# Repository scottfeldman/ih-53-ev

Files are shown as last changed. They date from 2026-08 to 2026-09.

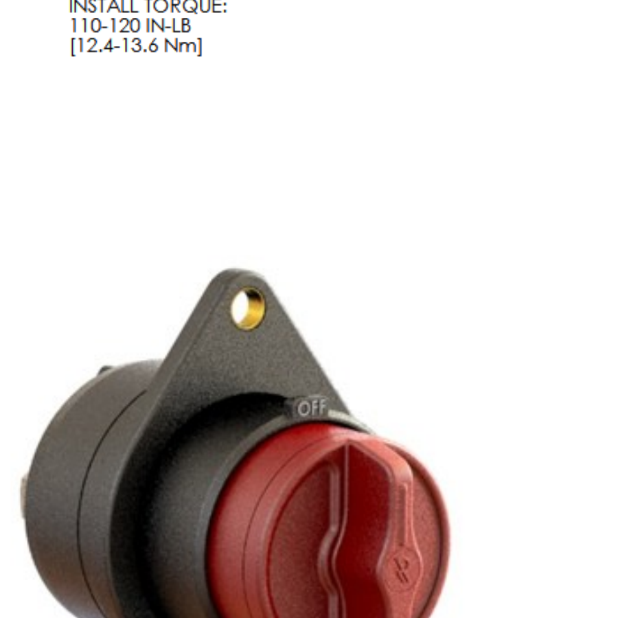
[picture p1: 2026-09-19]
bus bars/photo.png

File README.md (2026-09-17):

# ih-53-ev

1953 International Harvester EV conversion

### Dashboard

Pi 5 + PiCAN 3 instrument panel (Go / Fiber / HTMX): see [`dashboard/README.md`](dashboard/README.md).

### References

[https://www.orionbms.com/manuals/pdf/orionbms2_wiring_manual.pdf](https://www.orionbms.com/manuals/pdf/orionbms2_wiring_manual.pdf)
[https://www.orionbms.com/charger-integration/interfacing-tsm2500-chargers/](https://www.orionbms.com/charger-integration/interfacing-tsm2500-chargers/)
[https://www.thunderstruck-ev.com/images/companies/1/Chargers/ThunderStruck-TSM2500-ManualV1.09.pdf](https://www.thunderstruck-ev.com/images/companies/1/Chargers/ThunderStruck-TSM2500-ManualV1.09.pdf)
[https://www.go-ev.com/PDFs/HyPer_System_User_Manual_RevA_1.pdf](https://www.go-ev.com/PDFs/HyPer_System_User_Manual_RevA_1.pdf)
[https://www.bluesea.com/products/5032/ST_Blade_Split_Bus_Fuse_Block](https://www.bluesea.com/products/5032/ST_Blade_Split_Bus_Fuse_Block)
[https://www.fastandquiet.com/downloadable/600w-dc-dc-converter-isolated-dcis-schematic.PDF](https://www.fastandquiet.com/downloadable/600w-dc-dc-converter-isolated-dcis-schematic.PDF)
[https://www.ewertenergy.com/products/candapter/downloads/candapter_manual.pdf](https://www.ewertenergy.com/products/candapter/downloads/candapter_manual.pdf)
[https://www.raspberrypi.com/products/raspberry-pi-5/](https://www.raspberrypi.com/products/raspberry-pi-5/)
[https://www.raspberrypi.com/products/touch-display-2/](https://www.raspberrypi.com/products/touch-display-2/)
[https://www.raspberrypi.com/documentation/accessories/touch-display-2.html](https://www.raspberrypi.com/documentation/accessories/touch-display-2.html)
[https://www.raspberrypi.com/software/](https://www.raspberrypi.com/software/)

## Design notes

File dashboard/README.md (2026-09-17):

# IH-53 EV dashboard

Go + Fiber + HTMX + Gomponents instrument panel for the Raspberry Pi 5 + PiCAN 3.

Listens on `:10000`, talks **SocketCAN** `can0` at **250 kbps** (BMS-side CAN1 tap). Orion remains the TSM2500 charge master. The dash is **listen-only** for telemetry (Orion broadcasts + TSM2500 status + HyPer TPDOs). The only optional TX is **confirm-clear Orion DTCs** (OBD2 Mode `$04`).

## Hardware

- Pi 5 + [PiCAN 3](https://www.skpang.co.uk/collections/hats/products/pican3-can-bus-board-for-raspberry-pi-4-with-3a-smps-rtc)
- Tap **CAN-PI-H / CAN-PI-L** on Orion CAN1 (same net as CANdapter / TSM2500), **not** the HyPer side of the BB-CANOP isolator — see [`schematic/wires.md`](../schematic/wires.md) §8.5
- PiCAN **120 Ω jumper open** (Orion + HyPer already terminate)
- Bitrate **250000** — ignore `500000` in the [PiCAN Python examples](https://github.com/skpang/PiCAN-Python-examples)

SocketCAN bring-up is done by **systemd-networkd**, not by the process.

## Dev (Mac)

```bash
cd dashboard
GOWORK=off go run ./cmd/dashboard --demo --listen :10000
```

## Build for Pi 5

```bash
cd dashboard
GOWORK=off GOOS=linux GOARCH=arm64 go build -o ih53ev-dashboard ./cmd/dashboard
```

## Install on Pi

Fresh [Raspberry Pi 5](https://www.raspberrypi.com/products/raspberry-pi-5/) plus the official [Touch Display 2 10″](https://www.raspberrypi.com/products/touch-display-2/) (1200×1920). Connection steps: [Touch Display 2 docs](https://www.raspberrypi.com/documentation/accessories/touch-display-2.html). Vehicle wiring (PiCAN 3 SMPS, SW5, CAN tap): [`schematic/wires.md`](../schematic/wires.md) §11.

**PiCAN 3:** the HAT covers the same 5 V/GND pins the display pigtail uses. Use a stacking header and pick 5 V/GND off the top, or tap 5 V/GND on the PiCAN to display J1. In the truck, power from the PiCAN **3 A SMPS** only — do **not** also plug USB-C into the Pi. Leave USB empty.

Flash [Raspberry Pi OS](https://www.raspberrypi.com/software/) (64-bit, **desktop** — not Lite). Enable SSH in Imager customisation.

```bash
git clone https://github.com/scottfeldman/ih-53-ev.git
cd ih-53-ev/dashboard
sudo ./install.sh
sudo reboot
```

`install.sh` builds the dash, enables it on boot as fullscreen Chromium kiosk, and matches the current desktop: landscape 10″ panel, taskbar at the bottom, solid red background, dash icon centered. Reboot is required so the PiCAN overlay can create `can0`; until then the app exits and the browser has nothing to open. After reboot, Chromium fills the screen. Tap **Desktop** (then confirm) to leave kiosk; open **IH-53 EV Dashboard** from the Raspberry menu or the desktop icon to return. If the image is sideways the wrong way, change `DISPLAY_TRANSFORM` in `install.sh` from `90` (Left) to `270` (Right) and re-run.

## Flags

| Flag | Default | Meaning |
|---|---|---|
| `--iface` | `can0` | SocketCAN interface |
| `--listen` | `:10000` | HTTP bind |
| `--demo` | off | Synthetic state, no CAN |
| `--canmap` | auto | Orion + HyPer layout YAML |
| `--log-can` | off | Log every RX frame |

## Orion broadcasts (CAN1)

Telemetry is **push**, not OBD2 poll — so the laptop Orion utility can stay on CAN1 without fighting the dash.

Program custom messages in the Orion utility (**CANBUS Settings → Edit CANBUS Messages**) to match [`canmap.yaml`](canmap.yaml). Standard 11-bit IDs, **big-endian**, CAN1:

| ID | Rate | Contents |
|----|---|---|
| `0x350` | 100 ms | SOC % (u8), pack V (u16 ×0.1), pack A (i16 ×0.1) |
| `0x351` | 100 ms | CCL, DCL (u16 A), high/low/avg temp (°C i8) |
| `0x352` | 500 ms | cell min/max (u16 ×0.0001 V), pack cycles, fault count |

**Cell broadcast** (all 30 taps): Orion utility → CANBUS Settings → **Enable Battery Cell Broadcast** on CAN1, ID **`0x36`** (matches `canmap.yaml`). Each frame is one tap: ID, instant V, IR + shunt bit, open V, checksum. The Detail page shows a **5×6** grid (modules × taps).

For Pack SOC in the utility, set **Then Divide By = 2** so the bus carries whole percent (matches `scale: 1` in the YAML).

The dash does **not** continuously use `0x7E3` / `0x7EB`. Those stay free for the CANdapter utility.

## HyPer X1 TPDOs

Program in TAU SmartView (do not add Node ID). See `hyper:` in [`canmap.yaml`](canmap.yaml): `0x190` / `0x191` / `0x192`.

## TSM2500

Listen-only status `0x18EB2440`. Never transmits `0x18E54024`.

## Commands from the dash?

| Action | On bus? | Notes |
|---|---|---|
| Read SOC / V / A / temps / cells summary | No TX | Orion broadcasts |
| Read charger / X1 | No TX | Status / TPDOs |
| Set charge V/A | **Never** | Orion owns TSM2500 |
| Drive / throttle | **Never** | Analog throttle |
| Clear Orion DTCs | Optional TX | Mode `$04` once; unplug utility first |

Normal operation is **read-only**. Clear-faults is the only command worth keeping on the dash.

## Safety

- Stale sources show **NO DATA**, not the last good value
- Fault clear is POST + browser confirm + `confirm=yes`
- CANdapter and Pi share CAN1; OBD2 conflict only if you clear faults while the utility is live

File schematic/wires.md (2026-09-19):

# IH-53 EV wiring list

Physical wires taken from `IH53EV.kicad_sch`. Size/type is the schematic text on that run when present. **Color prefers the component wiring-harness pigtail** and is carried through splices; schematic stroke color is ignored when a harness color exists.

Inline disconnects (Anderson, DJ70xx, Weather Pack, Deutsch, USB) are drawn as two-sided symbols. Each side is a separate cable termination; mating the housings is not a wire.

**Orion BMS 2 Main I/O** on this vehicle is the **CWHMIO 18 AWG** harness (Sumitomo 8240-4892 crimps), not 22 AWG.

## Color rules

1. If a factory harness / pigtail has a color, that color is the color of the whole run, including splices and bulkhead connectors.
2. When two pigtails meet (for example TSM2500 CAN into Orion CAN1), **keep the Orion (or other “bus owner”) color on the trunk**; the other pigtail keeps its factory color only up to the splice.
3. Traction **2/0 DLO** is **orange** (EV HV jacket). Polarity is **red** (+) / **black** (−) adhesive heatshrink at each lug — not a red/black jacket.
4. 12 V **GXL** (schematic: GLX) battery and DC-DC 12 V feeds have no colored pigtail: **red = +**, **black = −**.
5. Vehicle **DCIS pack HV** (10 AWG / 18 AWG HV from the 3-way toward the pack) is **red = +**, **black = −**. Factory DCIS pigtail stays **yellow / gray** only up to `dj70310-6.3-1`.
6. Orion CWHMIO colors: pin 1 (Always_On) = **green**, pin 2 (READY) = solid **blue**, and pin 3 (CHARGE) = solid **red** (2 and 3 from [Orion’s CANdapter troubleshooting page](https://www.orionbms.com/troubleshooting/problems-connecting-bms-unit-pc-software/); pin 1 from this harness). Pins 6, 7, 13, 14 from this vehicle’s harness. Remaining pins still **verify on harness card**.

## Wire key (from schematic)

| Code | Meaning |
| --- | --- |
| AWG | conductor size |
| TXL | 12 V / 48 V primary (18 AWG on this sheet) |
| GXL | 12 V 10 AWG (schematic label **GLX**) |
| HV | 600–1000 V DC pack (silicone / EV) |
| AC | J1772 / T92 mains (600 V) |
| 300VAC | RAC02 tap only (schematic may say 18AWG AC — same run) |
| DLO | traction / pack 2/0 |

## Harness color map (factory pigtails)

| Device | Pin / lead | Color | Size | Source |
| --- | --- | --- | --- | --- |
| Orion CWHMIO | 1 Always_On_Power | **green** | 18 AWG | this harness |
| Orion CWHMIO | 2 READY_Power | **blue** | 18 AWG | [Orion troubleshooting](https://www.orionbms.com/troubleshooting/problems-connecting-bms-unit-pc-software/) |
| Orion CWHMIO | 3 CHARGE_Power | **red** | 18 AWG | same |
| Orion CWHMIO | 6 Charger_Safety | **red/white** | 18 AWG | this harness |
| Orion CWHMIO | 7 DISCHARGE_enable | **blue/white** | 18 AWG | this harness |
| Orion CWHMIO | 12 Ground | **black** (typical; verify) | 18 AWG | CWHMIO; ground convention |
| Orion CWHMIO | 13 J1772_Control_Pilot | **orange/white** | 18 AWG | this harness |
| Orion CWHMIO | 14 J1772_Proximity_Detect | **brown/white** | 18 AWG | this harness |
| Orion CWHMIO | 17 CAN1_Shield | drain / bare | shield | CWHMIO CAN1 STP |
| Orion CWHMIO | 18 CAN1_H | CAN1 pair (gray jacket STP; inner *verify*) | 18 AWG pair, 12 ft | [purchasing guide](https://www.orionbms.com/manuals/pdf/orionbms2_purchasing_guide.pdf) |
| Orion CWHMIO | 19 CAN1_L | CAN1 pair (with pin 18) | 18 AWG pair, 12 ft | same |
| TSM2500 AC | L / N / PE | **brown** / **blue** / **green-yellow** | 2.5 mm² (~14 AWG) | [TSM2500 manual](https://www.thunderstruck-ev.com/images/companies/1/Chargers/ThunderStruck-TSM2500-ManualV1.09.pdf) |
| TSM2500 DC | + / − | **red** / **black** | 6 mm² (~10 AWG **HV**, not TXL) | same (SB50); pack voltage |
| TSM2500 CAN | H / L | **green/white** / **blue/white** | 0.5 mm² | same; [Orion TSM2500 note](https://www.orionbms.com/charger-integration/interfacing-tsm2500-chargers/) (splice onto Orion CAN1 colors) |
| DCIS output | + / − | **red** / **black** | 6.0 mm² (~10 AWG) | [DCIS schematic](https://www.fastandquiet.com/downloadable/600w-dc-dc-converter-isolated-dcis-schematic.PDF) |
| DCIS input | + / − | factory **yellow** / **gray**; vehicle **red** / **black** | 10 AWG **HV** (factory pigtail 1.5 mm²) | factory pigtail to 3-way; vehicle HV is red/black |
| DCIS key | Key_Switch_Control | **green** | 0.5 mm² | same |
| HyPer 9 encoder (not on this sheet) | K1-35 / 21 / 33 / 9 | red / yellow / green / black | 18 / 20 AWG | [HyPer manual](https://www.go-ev.com/PDFs/HyPer_System_User_Manual_RevA_1.pdf) |
| HyPer 9 K1 CAN, K1-24, K1-25, K1-26 | — | *verify on K1 print* (colors vary by kit) | 18–20 AWG | HyPer manual: identify by pin number |
| HyPer 9 B+ / B− | DC lugs | **orange** jacket; red / black HS | 2/0 DLO | EV orange; polarity by heatshrink |
| CANdapter USB | cable | black jacket (USB 2.0) | USB | CANdapter |

## Connector reference

| Device | Mating connector | Contacts / wire | Source |
| --- | --- | --- | --- |
| Orion BMS 2 Main I/O | TE 1376360-1 | **18 AWG** + Sumitomo 8240-4892 (this harness) | user; [Orion wiring manual](https://www.orionbms.com/manuals/pdf/orionbms2_wiring_manual.pdf) |
| Orion voltage taps (cell taps, not drawn as wires on this sheet) | TE 1318389-1 | 22 AWG + TE 1123343-2 (gold); group colors orange / red / yellow, grounds black | same |
| HyPer 9 X1 K1 | TE AMPSEAL 35-pin 776164-1, pins 770854-1 | typically 18–20 AWG | [HyPer System User Manual](https://www.go-ev.com/PDFs/HyPer_System_User_Manual_RevA_1.pdf) |
| HyPer 9 B+ / B− | inverter DC lugs | 2/0 DLO, ring terminal | schematic |
| TSM2500 AC input | DJ7031-4.8 (`DJ7031-4.8`; 4.8-11 / 4.8-21) | 2.5 mm² (~14 AWG) brown / blue / green-yellow | TSM2500 manual; schematic |
| TSM2500 DC output | Anderson SB50 (`AndersonSB50`) | 6 mm² (~10 AWG **HV**) red / black | same |
| TSM2500 CAN | charger CAN pair | 0.5 mm² green/white + blue/white | same |
| DCIS 600 W output | DJ7021-8-21 (`DJ7021-8-1`) | 6.0 mm² factory; vehicle **10 AWG GXL** red / black | DCIS schematic; schematic |
| DCIS 600 W input / enable | dj70310-6.3-11 (`dj70310-6.3-1`) | 10 AWG **HV** vehicle red / black (factory 1.5 mm² yellow / gray); 18 AWG **HV** / 0.5 mm² green key | this vehicle / DCIS schematic |
| CANdapter CAN | DE-9 (DB9) | twisted pair to pins 7 (CAN_H) and 2 (CAN_L) | [CANdapter manual](https://www.ewertenergy.com/products/candapter/downloads/candapter_manual.pdf) |
| CANdapter USB | USB-B on adapter | USB cable | CANdapter manual |
| Blue Sea 5032 buses | #10-32 stud | ring terminal | [Blue Sea 5032](https://www.bluesea.com/products/5032/ST_Blade_Split_Bus_Fuse_Block) |
| Blue Sea 5032 circuits | #8-32 screw | ring or spade | same |
| J1772 inlet | SAE J1772 socket | AC pins + CP / PP | schematic |
| Anderson 350 A / 600 V | SB350 housing | 2/0 contacts | schematic |
| Anderson SB50 | SB50 housing | 6–10 AWG contacts | TSM2500 DC only |
| DJ7021-8-21 | 2-way, 8.0 mm | DCIS 12 V output | schematic (included with DCIS) |
| dj70310-6.3-11 | 3-way, 6.3 mm | DCIS pack input / key | schematic (included with DCIS) |
| DJ7031-4.8 | 3-way, 4.8 mm | TSM2500 AC | schematic (included with TSM2500) |
| Delphi Weather Pack 4 | Weather Pack 4-way | 18 AWG (Orion colors carried through) | schematic |
| Deutsch DTM 3 | DTM 3-way | 16–22 AWG | schematic |
| BB CANOP isolator | terminal-block CAN / power | no factory pigtail color | Advantech BB-CANOP |
| HV terminal blocks (TB1/TB3 +, TB2 −) | 5/16″ and **1/4-20** studs | 2/0 lugs on 5/16″; 10/18 AWG HV on 1/4″ | schematic |
| Gigavac GV200QA-1 | M8 HV terminals; coil X1/X2 | 2/0 lugs; coil from K1 harness | schematic |
| T92P11D22-12 | 0.250″ QC | 14 AWG AC; 18 AWG coil from Orion | TE T92 |
| T9AP1D52-12 | 0.250″ QC | 18 AWG where tied to Orion | TE T9A |
| G9EJ-1-E-UVD DC12 | 0.250″ QC | 18 AWG HV contacts (polarized 3+/4−); 18 AWG TXL coil | Omron G9EJ |
| Cole Hersee 24213 | stud contacts; QC coil | 10 AWG GXL contacts | schematic |
| MAXI 5006 | MAXI fuse holder lugs | 10 AWG GXL | schematic |
| A25X500-4 | bolted fuse | 2/0 DLO lugs | schematic |

---

## 1. Traction pack (2/0 DLO)

Tesla modules **BT2–BT6** in series. Inter-module runs are unlabeled next to the modules; 2/0 DLO labels sit on that pack string. Jacket is **orange** (EV HV). Mark every lug with **red** (+) or **black** (−) adhesive heatshrink.

| ID | Size / type | Color | End A | A termination | End B | B termination |
| --- | --- | --- | --- | --- | --- | --- |
| HV-01 | 2/0 DLO | orange, black HS | BT2 − | module − lug | TerminalBlock2 5/16″ | 5/16″ stud, ring lug |
| HV-02 | 2/0 DLO | orange, red HS | BT2 + | module + lug | BT3 − | module − lug |
| HV-03 | 2/0 DLO | orange, red HS | BT3 + | module + lug | BT4 − | module − lug |
| HV-04 | 2/0 DLO | orange, red HS | BT4 + | module + lug | BT5 − | module − lug |
| HV-05 | 2/0 DLO | orange, red HS | BT5 + | module + lug | BT6 − | module − lug |
| HV-06 | 2/0 DLO | orange, red HS | BT6 + | module + lug | F4 (A25X500-4) | bolted fuse pad |
| HV-07 | 2/0 DLO | orange, red HS | F4 | bolted fuse pad | SW1 (Kill Switch HVBD6AXR) | switch HV terminal |
| HV-08 | — | — | SW1 output | **M10 stud through TB1** | TerminalBlock1 | bar clamp, no cable |
| HV-09 | 2/0 DLO | orange, red HS | TerminalBlock1 5/16″ | 5/16″ stud, ring lug | Anderson350A600V1 right + | SB350 contact (2/0) |
| HV-10 | 2/0 DLO | orange, black HS | TerminalBlock2 5/16″ | 5/16″ stud, ring lug | Anderson350A600V1 right − | SB350 contact (2/0) |
| HV-11 | 2/0 DLO | orange, red HS | Anderson350A600V1 left + | SB350 contact (2/0) | TerminalBlock3 5/16″ (pack + bus) | 5/16″ stud, ring lug |
| HV-12 | 2/0 DLO | orange, red HS | Anderson350A600V1 left − | SB350 contact (2/0) | HyPer 9 **B+** | inverter B+ lug |
| HV-13 | 2/0 DLO | orange, black HS | HyPer 9 **B−** | inverter B− lug | G1 (GV200QA-1) **A2−** | Gigavac M8 HV terminal |
| HV-14 | 2/0 DLO | orange, red HS | G1 **A1+** | Gigavac M8 HV terminal | TerminalBlock3 5/16″ (pack + bus) | 5/16″ stud, ring lug |

SB350 left housing mates to right housing: pack + bus ↔ TB1, inverter B+ ↔ TB2−.

### Bus bars TB1 / TB2 / TB3

Schematic symbols `Terminal_Block+` (TB1, TB3) and `Terminal_Block−` (TB2). TB2/TB3: **two 5/16″-18** (2/0) and **two 1/4-20**. TB1 replaces one 5/16″ with an **M10** clearance for SW1 (HVBD6AXR) output stud ([datasheet](https://downloads.rinconpower.com/hvbd-series-datasheet.pdf): 2× M10, 31.8 mm c-c, 19.1 mm thread). The other SW1 stud hangs off the bar for HV-07.

Same copper blank for all three; landings:

| Bar | Net | 5/16″ / M10 A | 5/16″ B | 1/4-20 A | 1/4-20 B |
| --- | --- | --- | --- | --- | --- |
| TB1 | pack + (rear / Anderson) | **SW1 M10 stud** (was HV-08) | HV-09 (SB350 +) | CH-DC+2 (32 A breaker) | DC-IN+2 (CB4) |
| TB2 | pack − | HV-01 (BT2 −) | HV-10 (SB350 −) | CH-DC−2 (CB3) | DC-IN−2 (10 A breaker) |
| TB3 | pack + (inverter / G1) | HV-11 (SB350 left +) | HV-14 (G1 A1+) | PC-01 (precharge) | unused |

Physical part: C110 copper **1/4″ × 2-1/2″ × 3.54″** (63.5 × 90 × 6.35 mm). TB2/TB3: two **5/16″-18** and two **1/4-20**. TB1: one **M10** (SW1 output), one **5/16″-18** (HV-09), two **1/4-20**. **SM40-M10** offset toward the 1/4-20 end. See FreeCAD `bus bars/bus bars.FCStd`.

Cell taps on BT2–BT6 are **not** wired on this sheet. Orion tap harness is 22 AWG to TE 1318389-1 (orange / red / yellow groups, black grounds). Schematic notes **internally termination** at the modules.

---

## 2. Charger HV DC

TSM2500 DC is the included **Anderson SB50** (`AndersonSB50`). Mating is not a wire: left housing is the charger pigtail, right housing is the vehicle. Pigtail colors **red / black** carry through. Vehicle runs are **10 AWG HV** (labeled). Factory pigtail is 6 mm² (~10 AWG) unlabeled on the charger side of the SB50.

SB50 mates top-to-top: charger **+** (left top) → vehicle right top → 32 A 2-pole → TerminalBlock1 **1/4-20** (pack +). Charger **−** (left bottom) → vehicle right bottom → Circuit_Breaker3 → TerminalBlock2 **1/4-20** (pack −).

| ID | Size / type | Color | End A | A termination | End B | B termination | Source |
| --- | --- | --- | --- | --- | --- | --- | --- |
| CH-DC+ | 6 mm² charger pigtail | red | TSM2500 **DC_Output_+** | charger DC + | AndersonSB50 left top | SB50 contact | TSM2500 pigtail |
| CH-DC− | 6 mm² charger pigtail | black | TSM2500 **DC_Ouput_−** | charger DC − | AndersonSB50 left bottom | SB50 contact | TSM2500 pigtail |
| CH-DC+V | 10 AWG HV | red | AndersonSB50 right top | SB50 contact | 2Pole_1000V_DC_32Amp1 B | breaker HV terminal | carry TSM2500 red |
| CH-DC+2 | 10 AWG HV | red | 2Pole_1000V_DC_32Amp1 A | breaker HV terminal | TerminalBlock1 1/4-20 | 1/4″ stud, ring lug | carry TSM2500 red |
| CH-DC−V | 10 AWG HV | black | AndersonSB50 right bottom | SB50 contact | Circuit_Breaker3 B | breaker HV terminal | carry TSM2500 black |
| CH-DC−2 | 10 AWG HV | black | Circuit_Breaker3 A | breaker HV terminal | TerminalBlock2 1/4-20 | 1/4″ stud, ring lug | carry TSM2500 black |

---

## 3. DC-DC converter (pack → 12 V)

DCIS factory connectors are drawn: **dj70310-6.3-11** (`dj70310-6.3-1`) 3-way input/key, **DJ7021-8-21** (`DJ7021-8-1`) 2-way 12 V output. Mating is not a wire. Factory pigtail stays **yellow / gray / green** only to the 3-way. Vehicle pack HV from that connector is **red / black**. Key stays **green**. 12 V output is **red / black**.

Pack input vehicle runs are **10 AWG HV** (same cable as charger DC). Factory pigtail to the 3-way is 1.5 mm². Key is pack voltage (DCIS: “key switch control voltage is consistent with the input voltage”), so the vehicle key run and the K4 tap are **18 AWG HV**, not TXL. 12 V output vehicle runs are **10 AWG GXL** (labeled GLX). If 10 AWG HV will not enter the 6.3 mm contacts, splice a short 14–16 AWG tail into the housing.

dj70310 pin order top → bottom: Input+ / Input− / Key. DJ7021 pin order top → bottom: Output+ / Output−. Left = DCIS pigtail, right = vehicle on the 3-way; **right = DCIS pigtail, left = vehicle** on the 2-way (as drawn).

| ID | Size / type | Color | End A | A termination | End B | B termination | Source |
| --- | --- | --- | --- | --- | --- | --- | --- |
| DC-IN0+ | 1.5 mm² factory pigtail | yellow | DCIS **Input+** | DCIS 3-pin | dj70310-6.3-1 left top | 6.3 mm contact | DCIS yellow |
| DC-IN0− | 1.5 mm² factory pigtail | gray | DCIS **Input−** | DCIS 3-pin | dj70310-6.3-1 left mid | 6.3 mm contact | DCIS gray |
| DC-KEY0 | 0.5 mm² factory pigtail | green | DCIS **Key_Switch_Control** | DCIS 3-pin | dj70310-6.3-1 left bottom | 6.3 mm contact | DCIS green |
| DC-IN+ | 10 AWG HV | red | dj70310-6.3-1 right top | 6.3 mm contact | Circuit_Breaker4 A | breaker HV terminal | vehicle HV+ |
| DC-K4TAP | 18 AWG HV | red | splice on DC-IN+ | — | K4 pin 3 (+) | G9EJ #250 QC | pack + to key relay |
| DC-IN+2 | 10 AWG HV | red | Circuit_Breaker4 B | breaker HV terminal | TerminalBlock1 1/4-20 | 1/4″ stud | vehicle HV+ |
| DC-IN− | 10 AWG HV | black | dj70310-6.3-1 right mid | 6.3 mm contact | 2Pole_1000V_DC_10Amp1 A | breaker HV terminal | vehicle HV− |
| DC-IN−2 | 10 AWG HV | black | 2Pole_1000V_DC_10Amp1 B | breaker HV terminal | TerminalBlock2 1/4-20 | 1/4″ stud | vehicle HV− |
| DC-KEY | 18 AWG HV | green | dj70310-6.3-1 right bottom | 6.3 mm contact | K4 pin 4 (−) | G9EJ #250 QC | carry DCIS green |
| DC-OUT+ | 6.0 mm² factory pigtail | red | DCIS **Output+** | DCIS 2-pin | DJ7021-8-1 right top | 8.0 mm contact | DCIS red |
| DC-OUT− | 6.0 mm² factory pigtail | black | DCIS **Output−** | DCIS 2-pin | DJ7021-8-1 right bottom | 8.0 mm contact | DCIS black |

Precharge path from pack + into the inverter (no pigtail). Schematic unlabeled; **18 AWG HV** (T9A QC), **red**. Circuit_Breaker2 is **1-pole 1000 V DC 10 A**.

| ID | Size / type | Color | End A | A termination | End B | B termination |
| --- | --- | --- | --- | --- | --- | --- |
| PC-01 | 18 AWG HV (unlabeled) | red | TerminalBlock3 1/4-20 | 1/4″ stud | Circuit_Breaker2 | breaker HV terminal |
| PC-02 | 18 AWG HV (unlabeled) | red | Circuit_Breaker2 | breaker HV terminal | K2 (T9AP1D52-12) pin 4 | T9A QC |
| PC-03 | 18 AWG HV (unlabeled) | red | K2 pin 3 | T9A QC | HyPer 9 **Precharge/Key_Switch_In** (K1-24) | AMPSEAL 776164-1 pin 24 |

K1-24 is the only HyPer 9 K1 pin that sees pack voltage on a non-isolated X1 (HyPer manual). If the K1 pigtail for pin 24 is a different color, use that K1 color instead of red from the splice to the AMPSEAL.

---

## 4. J1772 / charger AC

TSM2500 AC is the included **DJ7031-4.8** (`DJ7031-4.8`). Right housing is the charger pigtail (**brown / blue / green-yellow**); left is vehicle **14 AWG AC**. Those colors carry through the T92 to the J1772 inlet.

RAC02-12SE/277 is 2 W (≈47 mA at 115 VAC). Do **not** run 14 AWG AC to F7 / RAC02. Tap **18 AWG 300VAC** off the L1/L2 mains and fuse it at F7 (F5×20, 1 A / Recom T1A slow-blow).

DJ7031 pin order top → bottom: L / N / PE.

| ID | Size / type | Color | End A | A termination | End B | B termination |
| --- | --- | --- | --- | --- | --- | --- |
| AC-L1 | 14 AWG AC | brown | J1772 **L1** | J1772 inlet L1 | T92 pin 24 | 0.250″ QC |
| AC-L1-F7 | 18 AWG 300VAC | brown | splice on AC-L1 | — | F7 (F5×20, 1 A max) | fuse clip |
| AC-L1-RAC | 18 AWG 300VAC | brown | F7 | fuse clip | RAC02 **VAC_IN(L)** | RAC02 AC pin |
| AC-L2 | 14 AWG AC | blue | J1772 **L2/N** | J1772 inlet L2/N | T92 pin 14 | 0.250″ QC |
| AC-L2-TAP | 18 AWG 300VAC | blue | splice on AC-L2 | — | RAC02 **VAC_IN(N)** | RAC02 AC pin |
| AC-GND | 14 AWG AC | green-yellow | J1772 **Equipment Ground** | J1772 inlet PE | DJ7031-4.8 left bottom *and* chassis GND | 4.8 mm contact / chassis |
| AC-CHG-L | 14 AWG AC | brown | T92 pin 23 | 0.250″ QC | DJ7031-4.8 left top | 4.8 mm contact |
| AC-CHG-N | 14 AWG AC | blue | T92 pin 13 | 0.250″ QC | DJ7031-4.8 left mid | 4.8 mm contact |
| AC-CHG-L0 | 2.5 mm² charger pigtail | brown | DJ7031-4.8 right top | 4.8 mm contact | TSM2500 **AC_Input_Line** | charger AC pin 1 |
| AC-CHG-N0 | 2.5 mm² charger pigtail | blue | DJ7031-4.8 right mid | 4.8 mm contact | TSM2500 **AC_Input_Neutral** | charger AC pin 2 |
| AC-CHG-PE0 | 2.5 mm² charger pigtail | green-yellow | DJ7031-4.8 right bottom | 4.8 mm contact | TSM2500 **AC_Input_Earth_Ground** | charger AC pin 3 |

T92P11D22-12 (`Power_Relay1`) closes L1/L2 to the charger when the BMS charge coil is on.

---

## 5. 12 V vehicle battery and Blue Sea 5032

Battery / 12 V bus has no pigtail: **red = +**, **black = −**. F5 and F6 are both **MAXI 5006 50 A**. All 10 AWG 12 V runs are **GXL** (schematic **GLX**). 12 V feed from F6 is **red** to match DCIS output + through the mated DJ7021-8-21.

| ID | Size / type | Color | End A | A termination | End B | B termination |
| --- | --- | --- | --- | --- | --- | --- |
| 12-BAT+ | 10 AWG GXL | red | BT1 + (12 V vehicle battery) | battery + post | F5 (MAXI 50 A) *and* F6 (MAXI 50 A) (splice) | MAXI holder lug |
| 12-HOT | 10 AWG GXL | red | F5 | MAXI holder lug | Blue Sea **Always_Hot** bus *and* K3 (Cole Hersee 24213) pin 4 | #10-32 stud / solenoid stud |
| 12-SW | 10 AWG GXL | red | K3 pin 3 | solenoid stud | Blue Sea **Switched** bus | #10-32 stud |
| 12-DJ+ | 10 AWG GXL | red | F6 | MAXI holder lug | DJ7021-8-1 left top | 8.0 mm contact |
| 12-BAT− | 10 AWG GXL | black | BT1 − | battery − post | Blue Sea **Battery−** *and* DJ7021-8-1 left bottom *and* chassis GND | #10-32 stud / 8.0 mm / chassis |

DJ7021-8-1 left mates to right: 12 V battery +/− ↔ DCIS 12 V output +/− (red / black).

Ignition / inertia (coil side of K3). No factory harness; **red** = switched 12 V, **black** = ground.

| ID | Size / type | Color | End A | A termination | End B | B termination |
| --- | --- | --- | --- | --- | --- | --- |
| 12-IGN1 | 18 AWG TXL (unlabeled) | red | SW3 (Ignition) A | switch terminal | K3 pin 2 | Cole Hersee coil QC |
| 12-IGN2 | 18 AWG TXL (unlabeled) | red | SW3 B | switch terminal | SW4 (Inertia Switch) A | switch terminal |
| 12-KEY | 18 AWG TXL | red | SW4 B | switch terminal | Blue Sea **Key_Switch** circuit | #8-32 screw, ring/spade |
| 12-K3GND | 18 AWG TXL (unlabeled) | black | K3 pin 1 | coil QC | chassis GND | ring to chassis |

Dash **Instruments** (SW5) is Always_Hot, not this ignition chain — see §11.

K4 is **Omron G9EJ-1-E-UVD DC12** (schematic value). Coil is 12 V continuous on the READY rail (TXL), 100 mA / 1.2 W. Contacts close pack + onto the DCIS key (HV, signal current). Polarized contacts: pack + on terminal **3 (+)**, key on terminal **4 (−)**. Coil has no polarity. 0.250″ QC.

| ID | Size / type | Color | End A | A termination | End B | B termination |
| --- | --- | --- | --- | --- | --- | --- |
| 12-K4C | 18 AWG TXL (unlabeled) | black | K4 pin 1 | G9EJ coil QC | chassis GND | ring to chassis |
| 12-K4S | 18 AWG CWHMIO | **blue** (READY, pin 2) | K4 pin 2 | G9EJ coil QC | READY net (WP-R3) | see §7 |

---

## 6. Charge-control 12 V (RAC02 + T92 coil)

RAC02 has no colored pigtail. **Orion CWHMIO 18 AWG colors carry** onto the T92 coil.

| ID | Size / type | Color | End A | A termination | End B | B termination |
| --- | --- | --- | --- | --- | --- | --- |
| CHG-12+ | 18 AWG CWHMIO | **red** (CHARGE, pin 3) | RAC02 **+VOUT** | RAC02 DC pin | T92 **A1** *and* Orion **CHARGE_Power** pin 3 | 0.250″ QC / TE 1376360-1 pin 3 |
| CHG-12− | 18 AWG (unlabeled) | black | RAC02 **−VOUT** | RAC02 DC pin | chassis GND | ring to chassis |
| CHG-SAFE | 18 AWG CWHMIO | **red/white** (Charger_Safety, pin 6) | T92 **A2** | 0.250″ QC | Orion **Charger_Safety_(on/off)** pin 6 | TE 1376360-1 pin 6 |

---

## 7. Delphi Weather Pack 4 (12 V / BMS bulkhead)

4-way Weather Pack between the Blue Sea / K2 side and the Orion / CAN-isolator side. **Orion 18 AWG CWHMIO colors carry through both housings.** Schematic pin order is top → bottom.

**Right housing (BMS / isolator) — Orion pigtail side**

| ID | Size / type | Color | Weather Pack pin | End B | B termination |
| --- | --- | --- | --- | --- | --- |
| WP-R1 | 18 AWG CWHMIO | **black** (Ground, pin 12; verify) | right pin 1 (top) | BB CANOP **GND** *and* Orion **Ground** pin 12 | isolator / TE 1376360-1 pin 12 |
| WP-R2 | 18 AWG CWHMIO | **green** (Always_On, pin 1) | right pin 2 | Orion **Always_On_Power** pin 1 | TE 1376360-1 pin 1 |
| WP-R3 | 18 AWG CWHMIO | **blue** (READY, pin 2) | right pin 3 | Orion **READY_Power** pin 2 *and* BB CANOP **12V+** *and* K4 pin 2 | TE 1376360-1 pin 2 / isolator / G9EJ coil |
| WP-R4 | 18 AWG CWHMIO | **blue/white** (DISCHARGE_enable, pin 7) | right pin 4 (bottom) | Orion **DISCHARGE_enable** pin 7 | TE 1376360-1 pin 7 |

**Left housing (fuse block / K2) — same colors through the mate**

| ID | Size / type | Color | End A | A termination | Weather Pack pin |
| --- | --- | --- | --- | --- | --- |
| WP-L1 | 18 AWG | **black** (from pin 12) | Blue Sea **GND** circuit | #8-32 screw | left pin 1 (top) |
| WP-L2 | 18 AWG | **green** (Always_On) | Blue Sea **Always_On** circuit | #8-32 screw | left pin 2 |
| WP-L3 | 18 AWG | **blue** (READY) | Blue Sea **Ready/Precharge** *and* K2 pin 1 | #8-32 / T9A QC | left pin 3 |
| WP-L4 | 18 AWG | **blue/white** (DISCHARGE_enable) | K2 pin 2 | T9A QC | left pin 4 (bottom) |

Left mates to right, pin-for-pin.

---

## 8. CAN

Schematic: CAN1 250 kbps; **CAN shielding not terminated** on the inverter Deutsch. Orion CAN1 is a **12 ft shielded twisted pair** on the CWHMIO. Orion shield (pin 17) lands on the isolator. Shield grounded at one end only (Orion wiring manual).

**Trunk color = Orion CAN1 pair.** TSM2500 **green/white** (H) and **blue/white** (L) and CANdapter pigtails splice onto that pair and keep factory color only up to the splice.

### 8.1 HyPer 9 to Deutsch DTM 3

HyPer 9 K1 is AMPSEAL 776164-1. CAN_H = K1-13, CAN_L = K1-2. Standard K1 kits often leave K1-13 unpopulated — identify by **pin number**; colors vary.

| ID | Size / type | Color | End A | A termination | End B | B termination |
| --- | --- | --- | --- | --- | --- | --- |
| CAN-INV-H | 18–20 AWG K1 | *K1-13 harness — verify* | HyPer 9 **CAN_H** (K1-13) | AMPSEAL pin 13 | Deutsch DTM left pin 2 | DTM socket |
| CAN-INV-L | 18–20 AWG K1 | *K1-2 harness — verify* | HyPer 9 **CAN_L** (K1-2) | AMPSEAL pin 2 | Deutsch DTM left pin 3 | DTM socket |
| CAN-INV-SH | not terminated | — | Deutsch DTM left pin 1 | DTM socket | — | schematic: shield not terminated |

HyPer 9 **CAN_H_RES** (K1-14) is jumpered to **CAN_L_RES** (K1-3) on the schematic with note **internally termination**. That is the inverter termination jumper, not a harness cable.

### 8.2 Deutsch DTM 3 to BB CANOP (inverter side of isolator)

Carry the same K1 CAN colors through the DTM.

| ID | Size / type | Color | End A | A termination | End B | B termination |
| --- | --- | --- | --- | --- | --- | --- |
| CAN-ISO-1 | same as CAN-INV-* | *carry K1 CAN colors* | Deutsch DTM right pin 1 | DTM pin | BB CANOP pin 1 | isolator CAN TB |
| CAN-ISO-2 | same as CAN-INV-H | *carry K1-13* | Deutsch DTM right pin 2 | DTM pin | BB CANOP pin 2 | isolator CAN TB |
| CAN-ISO-3 | same as CAN-INV-L | *carry K1-2* | Deutsch DTM right pin 3 | DTM pin | BB CANOP pin 3 | isolator CAN TB |

### 8.3 BB CANOP (BMS side) to CAN1 bus

| ID | Size / type | Color | Ends | Terminations |
| --- | --- | --- | --- | --- |
| CAN1-H | 18 AWG CWHMIO CAN1 pair | Orion CAN1_H (pin 18; *verify inner*) | BB CANOP pin 6; Orion **CAN1_H** pin 18; CANdapter **CAN_H**; TSM2500 **CAN_H** (green/white pigtail to splice only) | isolator; TE 1376360-1 pin 18; CANdapter DB9 pin 7; charger CAN |
| CAN1-L | 18 AWG CWHMIO CAN1 pair | Orion CAN1_L (pin 19; *verify inner*) | BB CANOP pin 7; Orion **CAN1_L** pin 19; CANdapter **CAN_L**; TSM2500 **CAN_L** (blue/white pigtail to splice only) | isolator; TE 1376360-1 pin 19; CANdapter DB9 pin 2; charger CAN |
| CAN1-SH | shield drain | drain / bare | BB CANOP pin 5 | Orion **CAN1_Sheild** pin 17. Do not ground the shield elsewhere. |

### 8.4 CANdapter USB

| ID | Size / type | Color | End A | A termination | End B | B termination |
| --- | --- | --- | --- | --- | --- | --- |
| USB-1 | USB 2.0 cable | black jacket | CANdapter **USB** | USB-B on adapter | USBConnector1 | USB connector (vehicle / laptop) |

USBConnector1 has a second pin with a short unterminated stub on the schematic (no far-end device).

### 8.5 Dash PiCAN 3 (RPi 5 instrument panel)

Tap **BMS-side CAN1** (same net as CANdapter / Orion / TSM2500), not the Deutsch/HyPer side of the isolator. **120 Ω jumper on the PiCAN 3 stays open** — Orion and HyPer already terminate. Stub to the dash at 250 kbps; keep it twisted with the CAN1 pair.

| ID | Size / type | Color | End A | A termination | End B | B termination |
| --- | --- | --- | --- | --- | --- | --- |
| CAN-PI-H | 18–20 AWG STP | Orion CAN1_H (*verify inner*) | splice on **CAN1-H** | tap | PiCAN 3 **CAN_H** | screw / DB9 pin 7 |
| CAN-PI-L | 18–20 AWG STP | Orion CAN1_L (*verify inner*) | splice on **CAN1-L** | tap | PiCAN 3 **CAN_L** | screw / DB9 pin 2 |
| CAN-PI-G | 18 AWG TXL | black | PiCAN 3 **GND** | screw | chassis GND *or* WP-L1 ground | ring / splice |

---

## 9. J1772 pilot / proximity (Orion)

CWHMIO **18 AWG** colors carry from the I/O connector to the inlet.

| ID | Size / type | Color | End A | A termination | End B | B termination |
| --- | --- | --- | --- | --- | --- | --- |
| J1772-CP | 18 AWG CWHMIO | **orange/white** (Control_Pilot, pin 13) | Orion **J1772_Control_Pilot** pin 13 | TE 1376360-1 pin 13 | J1772 **Control Pilot** | J1772 CP pin |
| J1772-PP | 18 AWG CWHMIO | **brown/white** (Proximity_Detect, pin 14) | Orion **J1772_Proximity_Detect** pin 14 | TE 1376360-1 pin 14 | J1772 **Proximity Detect** | J1772 PP pin |

---

## 10. Contactor coils (HyPer 9 K1)

Use the **K1 harness color printed for that pin** (kits vary). No published color for K1-25 / K1-26 in the HyPer text manual.

| ID | Size / type | Color | End A | A termination | End B | B termination | Source |
| --- | --- | --- | --- | --- | --- | --- | --- |
| MC-X1 | 18–20 AWG K1 | *K1-25 harness — verify* | HyPer 9 **COIL_RETURN_+** (K1-25) | AMPSEAL 776164-1 pin 25 | G1 **X1** | Gigavac coil | HyPer K1 |
| MC-X2 | 18–20 AWG K1 | *K1-26 harness — verify* | HyPer 9 **DRIVER_OUT_1_−** (K1-26) | AMPSEAL 776164-1 pin 26 | G1 **X2** | Gigavac coil | HyPer K1 |

---

## 11. Dash instrument panel (RPi 5 / PiCAN 3 / SW5)

RPi 5 and PiCAN 3 live at the **front** (dash). They are **not** in the Ready/Precharge path. A Pi crash or a late boot does not drop Orion READY, K2, the isolator, or K4.

**SW5 Instruments** is a dash SPST on **Always_Hot** so the Pi can boot before the key. Blue Sea **Dash/Pi** is the Always_Hot fused circuit (circuit 4 on the Always_On half of the 5032) — not the Switched / Ready half.

Typical order: SW5 on → wait for the dash → key on. Orion Always_On is already live, so a booted Pi sees BMS CAN1 before READY. If the key comes first, missed startup frames are acceptable; poll Orion for current SOC / voltages / flags and continue.

Turn SW5 **off** when leaving. The Pi will flatten BT1 if left on; K4 / DC-DC only run after Ready.

**Display:** official **Raspberry Pi Touch Display 2 10″** (1200×1920, Pi 5 only). DSI FFC for video/touch. The supplied GPIO pigtail feeds the panel from the Pi **5 V / GND** pins (display `J1`). No separate screen PSU.

**5 V:** use the PiCAN 3 **3 A SMPS** (6–20 V in on the screw terminal). That rail also feeds the 10″ panel. Pi 5 + 10″ TD2 + PiCAN is typically ~8–12 W; 3 A is 15 W. Leave USB empty (header power makes the Pi assume 3 A and cap USB at 600 mA). Do **not** also plug USB-C into the Pi. If you see undervoltage, drop brightness or add a 5 A 5 V supply later.

The display pigtail wants the same 5 V header pins the HAT covers. Use a stacking header and pick 5 V/GND off the top, or tap 5 V/GND on the PiCAN to display `J1`. Do not run a second 5 V supply into those pins.

| ID | Size / type | Color | End A | A termination | End B | B termination |
| --- | --- | --- | --- | --- | --- | --- |
| 12-PI | 18 AWG TXL | red | Blue Sea **Dash/Pi** | #8-32 screw | SW5 A | switch terminal |
| 12-PISW | 18 AWG TXL | red | SW5 B | switch terminal | PiCAN 3 **+12 V** | screw terminal |
| 12-PIGND | 18 AWG TXL | black | PiCAN 3 **GND** | screw terminal | chassis GND | ring to chassis |

---

## Not wired on this sheet

| Item | Notes |
| --- | --- |
| Orion **Fan_Monitor_MPI3** pin 9, **Fan_Enable_MPO3** pin 10 | No-connect (leave CWHMIO tails capped) |
| Blue Sea 5032 fused circuits 1, 3 and unused 6 | Unused (circuit 5 is Key_Switch / 12-KEY; Always_Hot circuit 4 is **Dash/Pi**) |
| Tesla module cell taps | Separate Orion tap harness (22 AWG, orange / red / yellow, black grounds) |
| HyPer 9 motor phase / encoder / thermistor | Encoder: red / yellow / green / black as in HyPer manual |
| TSM2500 12 V aux, LED, drive-away, temp | Not on this schematic |

K4 is Omron **G9EJ-1-E-UVD DC12** (see §5). SW5 is the dash Instruments switch for the RPi 5 (see §11).

### CWHMIO pins still to read off the card

| Pin | Function | Color (from card) |
| --- | --- | --- |
| 12 | Ground (expect black) | |
| 18 / 19 | CAN1_H / CAN1_L inner | |

---

## Schematic check (2026-08-26)

Parsed `IH53EV.kicad_sch` after the terminal-block symbol change (**1/4″ studs**, `Terminal_Block+` / `Terminal_Block−`). Gaps left as documented:

- Traction 2/0 is **orange** with red/black heatshrink (vehicle convention; schematic stroke may still show +/−).
- Vehicle DCIS pack HV is **red / black** from the 3-way; factory pigtail stays yellow / gray.
- F5 and F6 are both **MAXI 5006 50 A**; all 10 AWG 12 V is **GXL** (sheet says GLX). Sheet wire key may still mention SGX.
- Precharge PC-01/02/03 has no size label; assigned **18 AWG HV** (T9A QC). Circuit_Breaker2 sheet text is **1Pole_1000V_DC_10Amp**.
- RAC02 / F7 taps: schematic has both **18AWG AC** and **18AWG 300VAC**; same runs as the wire key.
- DC-IN+ is one net with the K4 tap: **10 AWG HV** on breaker → stud, **18 AWG HV** at the tap (DC-K4TAP).
- Circuit_Breaker3 / Circuit_Breaker4 / 2-pole breakers have empty Value fields; ratings are from the reference / nearby text (32 A charger, 10 A DCIS).
- J1772 inlet instance reference is `J1773`.
- Unused: Blue Sea circuits 1, 3 and unused 6, Orion fan pins 9/10, Tesla cell-tap pins, one TerminalBlock3 **1/4-20** stud, USBConnector1 stub.
- RPi 5 + PiCAN 3 at the dash. SW5 **Instruments** feeds them from Always_Hot **Dash/Pi**. Ready/Precharge is not gated.
- HV junction studs: schematic `Terminal_Block+` / `Terminal_Block−` now read **1/4″ studs** plus **5/16″ studs**. TB1 and TB3 are the + symbol; TB2 is the − symbol.

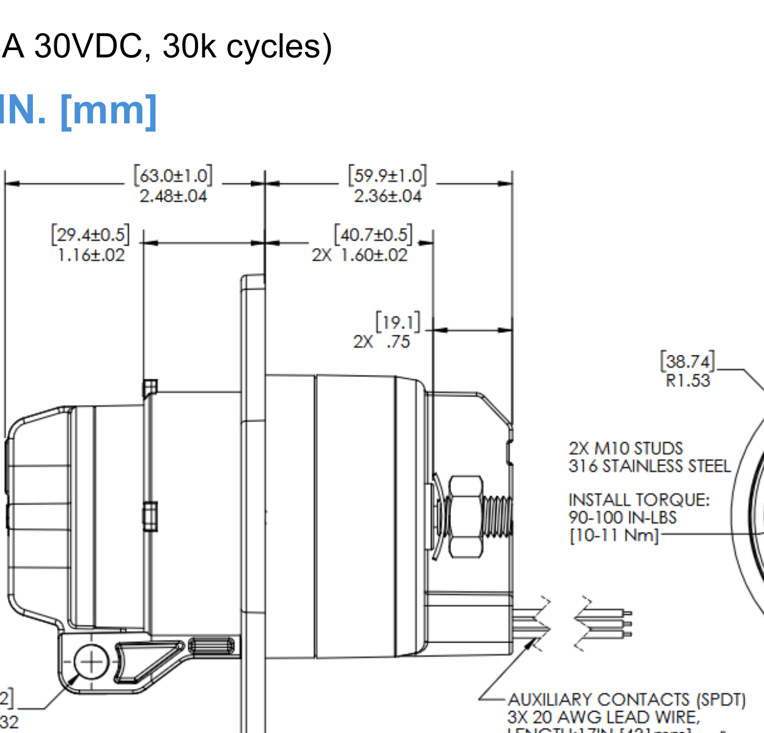
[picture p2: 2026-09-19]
bus bars/side.png

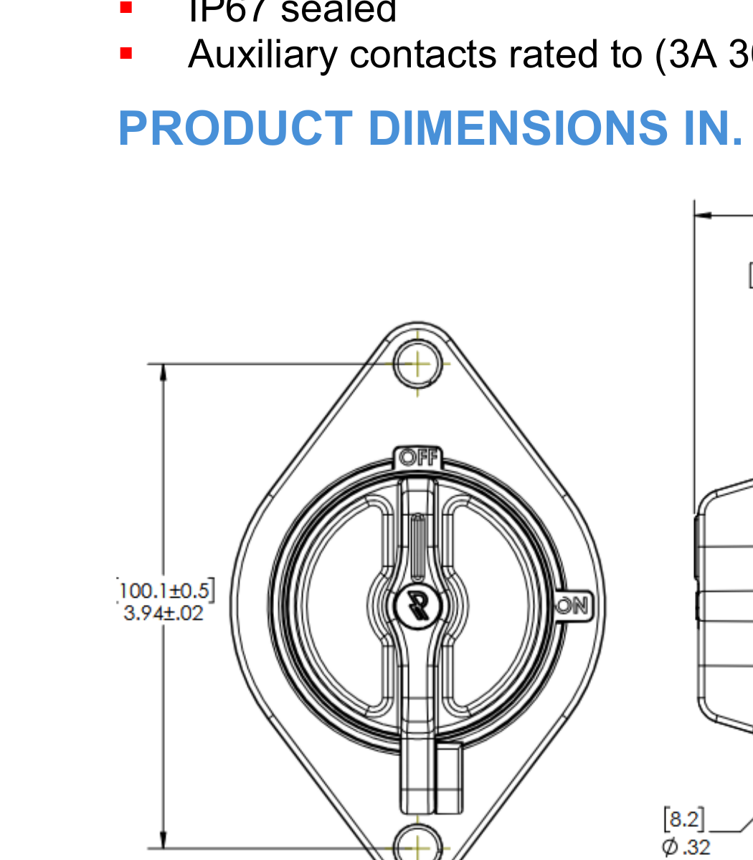
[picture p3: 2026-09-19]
bus bars/front.png

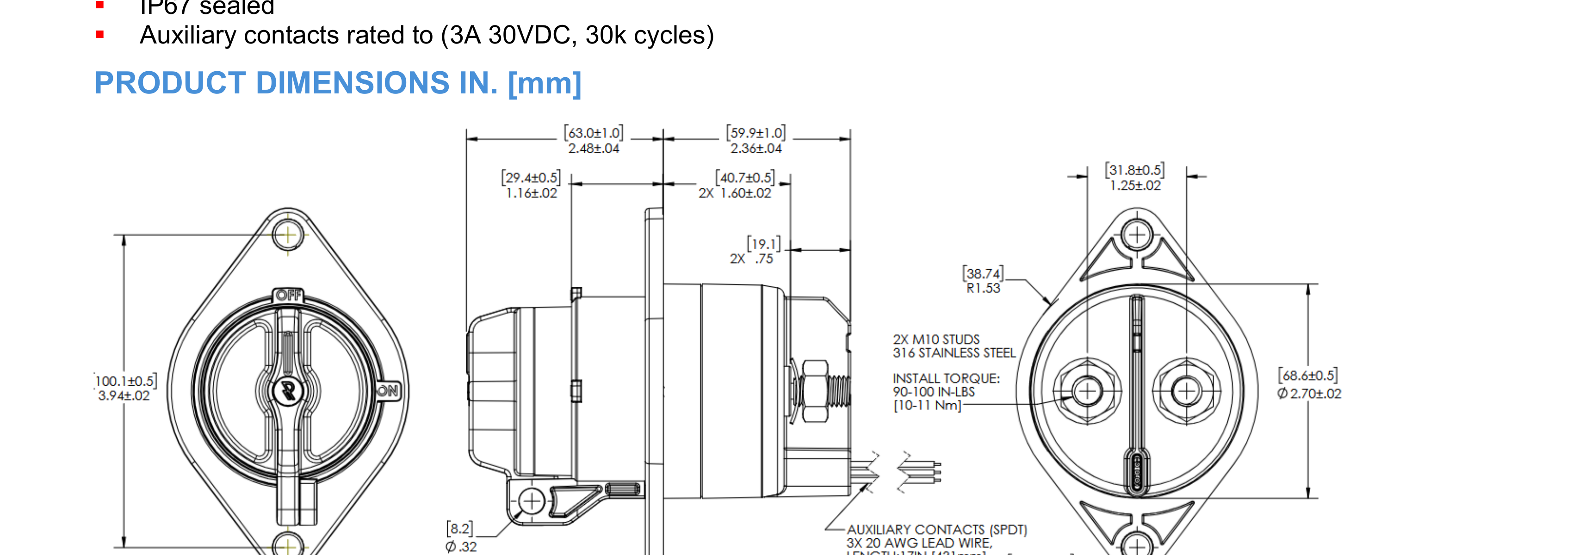
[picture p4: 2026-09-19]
bus bars/all3.png

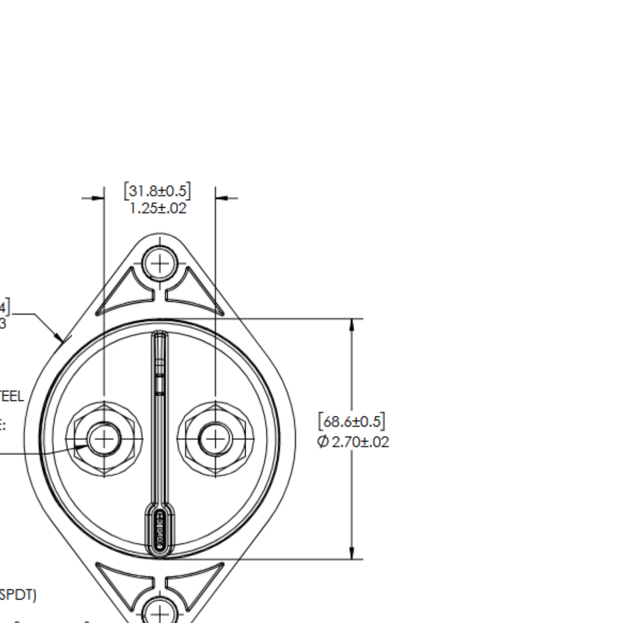
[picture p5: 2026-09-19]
bus bars/rear.png

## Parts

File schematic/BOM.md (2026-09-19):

# IH-53 EV bill of materials

Purchase list for the wiring in [`wires.md`](wires.md) / `IH53EV.kicad_sch`. Lengths are **buy quantities** (spool / cut with slack), not measured harness lengths.

**How to use:** skip anything already on the truck. Factory pigtails and their housings ship with the device — do not rebuy those halves. Buy the vehicle-side mate, contacts, and bulk wire.

Tesla modules **BT2–BT6** in series are ~108–126 V. HV insulation on this sheet is 600–1000 V; interrupting ratings must still be **DC** at pack voltage.

---

## 1. Major assemblies (confirm on hand)

| Qty | Item | MPN / spec | Used for | Status |
| --- | --- | --- | --- | --- |
| 5 | Tesla Model S battery modules | BT2–BT6 | traction pack | on hand |
| 1 | 12 V vehicle battery | BT1 | Blue Sea / DCIS 12 V | on hand / buy if needed |
| 1 | NetGain HyPer 9 + K1 AMPSEAL harness | AMPSEAL 776164-1 | inverter | on hand |
| 1 | Orion BMS 2 + **CWHMIO 18 AWG** Main I/O | TE 1376360-1, Sumitomo 8240-4892 | BMS | on hand |
| 1 | Orion cell-tap harness | TE 1318389-1, 22 AWG | module taps (not on this sheet) | on hand / separate |
| 1 | Thunderstruck TSM2500 | includes DJ7031-4.8 + SB50 pigtails | charger | on hand |
| 1 | Fast and Quiet DCIS 600 W | includes dj70310-6.3-11 + DJ7021-8-21 | pack → 12 V | on hand |
| 1 | Ewert CANdapter | DE-9 CAN, USB-B | CAN config | on hand |

---

## 2. Buy — HV switching and protection

| Qty | Item | MPN / spec | Used for | Where |
| --- | --- | --- | --- | --- |
| 1 | Pack fuse 500 A, bolted semiconductor | Mersen **A25X500-4** (500 A, 250 V) | F4, pack + | DigiKey / Mersen |
| 1 | Fuse block / pads for A25X (1.5″ dia, bolt-in) | match A25X500-4 | F4 mounting | with fuse |
| 1 | Manual HV battery disconnect, 600 A, red handle, no aux | Rincon **HVBD6AXR** | SW1 kill switch | Rincon / EV distributors |
| 1 | HV contactor, 12 V coil, M8 power terminals | Gigavac / Sensata **GV200QA-1** | G1 pack + | Gigavac / EV distributors |
| 1 | Precharge / discharge relay, 12 V coil, SPST-NO, #250 QC | TE Potter & Brumfield **T9AP1D52-12** | K2 | DigiKey / Mouser |
| 1 | Charger AC relay, 12 V coil, DPDT, #250 QC | TE Potter & Brumfield **T92P11D22-12** | Power_Relay1 | DigiKey / Mouser |
| 1 | Pack-voltage key relay, 12 V coil, 400 V DC / 15 A, polarized contacts 3+ / 4− | Omron **G9EJ-1-E-UVD DC12** | K4 DCIS key | DigiKey / Mouser (not Amazon cube relays) |
| 1 | 12 V continuous-duty solenoid, 200 A, insulated coil | Cole Hersee / Littelfuse **24213** (aka 24213-BX) | K3 switched 12 V | Waytek / NAPA |
| 1 | 2-pole **1000 V DC** breaker, **32 A** | schematic `2Pole_1000V_DC_32Amp1` + `Circuit_Breaker3` (both poles of one breaker) | TSM2500 DC +/− | PV/EV DC MCB (e.g. Noark Ex9BP 4P 1000 V class — confirm pole count vs 1000 V) |
| 1 | 2-pole **1000 V DC** breaker, **10 A** | schematic `2Pole_1000V_DC_10Amp1` + `Circuit_Breaker4` | DCIS pack +/− | same family |
| 1 | 1-pole **1000 V DC** breaker, **10 A** | schematic `Circuit_Breaker2` / sheet text `1Pole_1000V_DC_10Amp` | precharge | same family |
| 1 | MAXI fuse holder | Littelfuse **5006** | F5 | Waytek / DigiKey |
| 1 | MAXI fuse **50 A** | MAXI 50 A | F5, 12 V Always_Hot | same |
| 1 | MAXI fuse holder | Littelfuse **5006** | F6 | same |
| 1 | MAXI fuse **50 A** | MAXI 50 A | F6, DCIS 12 V feed | same |
| 1 | 5×20 mm fuse holder (panel or inline) | F5×20 | F7 | DigiKey |
| 5 | 5×20 mm fuse **1 A**, slow-blow (Recom T1A class) | schematic `F5x20 (1A max)` | F7 RAC02 | DigiKey (spares) |

Breaker Values are empty on the schematic; ratings above are from the reference designators and the `1Pole_1000V_DC_10Amp` note. Buy **DC-rated** PV/EV breakers, not AC-only DIN breakers.

---

## 3. Buy — 12 V, charge, CAN, inlet

| Qty | Item | MPN / spec | Used for | Where |
| --- | --- | --- | --- | --- |
| 1 | ST Blade split-bus fuse block | Blue Sea **5032** | Always_Hot / Switched / fused circuits | Blue Sea / West Marine |
| 1 | ATO/ATC fuse assortment 5–15 A | — | Blue Sea circuits actually used (Always_On, Ready/Precharge, Key_Switch, **Dash/Pi**). Circuits 1, 3 and unused 6 still open. | any |
| 1 | PCB AC/DC 2 W, 12 V out, 85–305 VAC | Recom **RAC02-12SE/277** (schematic `RAC02-12SE_277`). If NRND, successor in RAC02-E/277 or RAC02-SK 12 V 2 W | charge 12 V for T92 / Orion CHARGE | DigiKey / Mouser |
| 1 | CAN isolator | Advantech **BB-CANOP** | HyPer CAN ↔ Orion CAN1 | Advantech / DigiKey |
| 1 | SAE J1772 inlet (16–32 A) | any listed J1772 socket | AC + CP + PP (`J1773` on the sheet) | EVSE suppliers |
| 1 | Ignition / key SPST | schematic SW3 | K3 coil | automotive |
| 1 | Inertia / crash switch, SPST, NC or as wired | schematic SW4 | series with ignition | automotive (GM-style inertia) |
| 1 | Dash **Instruments** SPST | schematic SW5 | Always_Hot Dash/Pi → RPi 5 supply | automotive |
| 1 | USB bulkhead or USB-A/B extension | USBConnector1 | CANdapter USB | any |
| 1 | Raspberry Pi 5 (4–8 GB) | official Pi 5 | dash instrument panel | Pi / authorized |
| 1 | PiCAN 3 HAT with **3 A SMPS** | SK Pang / Copperhill PiCAN 3 | CAN1 tap + 5 V for Pi and display | Copperhill / SK Pang |
| 1 | Raspberry Pi **Touch Display 2 10″** | official, 1200×1920, includes DSI FFC + GPIO power pigtail | dash | Pi / authorized |
| 1 | 40-pin stacking header (extra-tall) | — | 5 V/GND out the top of the PiCAN for the display pigtail | any |
| 1 | 12 V → 5 V / 5 A USB-C (optional spare) | only if the 3 A SMPS browns out | fallback Pi + display power | automotive |

---

## 4. Buy — connectors (vehicle side)

Included pigtails: TSM2500 DJ7031 + SB50, DCIS dj70310 + DJ7021, Orion CWHMIO, HyPer K1. Buy mates / extra contacts only if you are building the vehicle half instead of splicing onto the pigtail.

| Qty | Item | MPN / spec | Used for |
| --- | --- | --- | --- |
| 1 pair | Anderson **SB350** housings, 350 A / 600 V | Anderson SB350 | pack / inverter disconnect |
| 4 | SB350 contacts for **2/0** | Anderson 2/0 contacts (e.g. 905-series) | HV-09…HV-12 |
| 1 | Anderson **SB50** housing + 2× contacts for **6–10 AWG / 6 mm²** | mate to TSM2500 DC pigtail | CH-DC+V / CH-DC−V |
| 1 | Weather Pack **4-way** kit (both housings, TPA, cable seals) | Aptiv 4-way line **12015797** (tower) + **12010974** (shroud), or 4-way square **12015798** + **12015024**; terminals **18 AWG** (socket 12089188 / pin 12089040 class) | DelphiWeather4Pack1 |
| 1 | Deutsch **DTM 3** kit | **DTM06-3S** + **DTM04-3P**, wedges WM-3S / WM-3P, pins 1060-16-0122, sockets 1062-16-0122 | inverter CAN bulkhead |
| 1 | DJ7031-4.8 vehicle half + 3× 4.8 mm contacts for **14 AWG** | mate to TSM2500 AC | AC-CHG-L/N/PE |
| 1 | dj70310-6.3-11 vehicle half + contacts: 2× **10 AWG HV** (or 14–16 AWG tails if 6.3 mm will not take 10 AWG), 1× **18 AWG HV** | mate to DCIS input/key | DC-IN+ (red), DC-IN− (black), DC-KEY (green) |
| 1 | DJ7021-8-21 vehicle half + 2× 8.0 mm contacts for **10 AWG** | mate to DCIS 12 V | 12-DJ+, 12-BAT− |
| — | Sumitomo **8240-4892** | only if extending/re-pinning CWHMIO | Orion Main I/O |

---

## 5. Buy — wire

Colors follow [`wires.md`](wires.md). **HV is 600–1000 V silicone / EV**, not TXL. Traction 2/0 is **orange**; polarity is heatshrink, not jacket color.

| Qty | Size / type | Color | Used for (wire IDs) |
| --- | --- | --- | --- |
| 45 ft | 2/0 DLO | **orange** | HV-01…HV-14 (all traction) |
| 18 ft | 10 AWG **GXL** (schematic GLX) | red | 12-BAT+, 12-HOT, 12-SW, 12-DJ+ |
| 8 ft | 10 AWG GXL | black | 12-BAT− |
| 20 ft | 10 AWG HV | red | CH-DC+V, CH-DC+2, DC-IN+, DC-IN+2 |
| 20 ft | 10 AWG HV | black | CH-DC−V, CH-DC−2, DC-IN−, DC-IN−2 |
| 8 ft | 18 AWG HV | red | DC-K4TAP, PC-01, PC-02, PC-03 |
| 8 ft | 18 AWG HV | green | DC-KEY |
| 15 ft | 14 AWG 600 V AC (THHN/MTW/SXL as preferred) | brown | AC-L1, AC-CHG-L |
| 15 ft | 14 AWG 600 V AC | blue | AC-L2, AC-CHG-N |
| 15 ft | 14 AWG 600 V AC | green-yellow | AC-GND |
| 5 ft | 18 AWG **300 VAC** (or 18 AWG AC as labeled) | brown | AC-L1-F7, AC-L1-RAC |
| 5 ft | 18 AWG 300 VAC | blue | AC-L2-TAP |
| 25 ft | 18 AWG TXL | red | 12-IGN1, 12-IGN2, 12-KEY, 12-PI, 12-PISW, leftover 12 V |
| 20 ft | 18 AWG TXL | black | 12-K3GND, 12-K4C, CHG-12−, 12-PIGND |
| 15 ft | 18–20 AWG STP | Orion CAN1 colors | CAN-PI-H / CAN-PI-L dash tap |
| 1 pack | 2/0 adhesive heatshrink | **red** | + ends of orange 2/0 |
| 1 pack | 2/0 adhesive heatshrink | **black** | − ends of orange 2/0 |

Do **not** buy TXL for charger DC, DCIS pack input, DCIS key, or precharge. Vehicle DCIS pack HV is the same **10 AWG HV** as charger DC (red / black). Factory pigtail stays yellow / gray.

Orion CWHMIO already supplies Always_On (green), READY (blue), CHARGE (red), Charger_Safety (red/white), DISCHARGE_enable (blue/white), CP (orange/white), PP (brown/white), CAN1 pair, and typically ground. Extend those tails rather than replacing them.

HyPer K1 already supplies CAN (K1-13 / K1-2), precharge/key (K1-24), and coil (K1-25 / K1-26) — splice or pin those colors; do not guess.

---

## 6. Buy — lugs and terminals

| Qty (min) | Item | Wire | Lands on |
| --- | --- | --- | --- |
| 12 | 2/0 ring, **5/16″** | 2/0 DLO | TB1/2/3 5/16″, module lugs, F4, SW1, SB350 |
| 4 | 2/0 ring, **M8** | 2/0 DLO | Gigavac A1+ / A2−, HyPer B+ / B− if M8 |
| 6 | 10 AWG HV ring, **1/4″** | 10 AWG HV | TB1 / TB2 1/4-20 studs (4 used + spares) |
| 2 | 18 AWG HV ring, **1/4″** | 18 AWG HV | TB3 1/4-20 precharge (+ spare) |
| 12 | 10 AWG HV ring, **1/4″ or M6** | 10 AWG HV | charger DC and DCIS breaker terminals (match breaker) |
| 4 | 18 AWG HV ring, **1/4″ or M6** | 18 AWG HV | Circuit_Breaker2 terminals (match breaker) |
| 8 | 10 AWG ring, **5/16″–24** | 10 AWG GXL | K3 studs, MAXI 5006, battery posts |
| 4 | 10 AWG ring, **#10-32** | 10 AWG GXL | Blue Sea Always_Hot / Switched / Battery− |
| 10 | 18 AWG ring or spade, **#8-32** | 18 AWG | Blue Sea circuits (incl. Dash/Pi) |
| 6 | 18 AWG ring, **#10** chassis | 18 AWG TXL / HV | chassis GND |
| 20 | 0.250″ QC (insulated), 14 AWG | 14 AWG AC | T92 pins 13/14/23/24 |
| 20 | 0.250″ QC (insulated), 18 AWG | 18 AWG | T92 A1/A2, T9A, G9EJ, Cole Hersee coil |
| 10 | 18 AWG HV 0.250″ QC | 18 AWG HV | G9EJ contacts 3/4, T9A pins 3/4 |
| 1 pack | heat-shrink, adhesive lined, 10 AWG through 18 AWG | — | every small lug |
| — | HV bus bars TB1/TB2/TB3 | 5/16″-18 + 1/4-20 | make — §6b |

---

## 6b. Buy / make — HV copper bus bars

Three identical C110 bars from one **1/4″ × 4″ × 12″** plate. TB1 and TB3 are pack **+**; TB2 is pack **−**. Blank is **2.50″ × 90 mm (3.54″)**. 2.5″ width gives two 2/0 palms 31.5 mm c-c so traction cables can approach at an angle. SM40 sits toward the 1/4-20 end; USS 1/4″ washers clear the 40 mm face (~34 mm c-c). 5/16″ washers still clear (~36 mm c-c). Section is ~403 mm².

| Qty | Item | MPN / spec | Used for |
| --- | --- | --- | --- |
| 3 | Copper bar blank | C110, **1/4″ × 2-1/2″ × 3.54″** (90 mm; from one 1/4″ × 4″ × 12″ plate) | TB1, TB2, TB3 |
| 5 | 5/16″-18 hex bolt, silicon bronze, **1-1/4″** | through-bolt + jam nut | 2/0 landings (TB1 has 1; TB2/TB3 have 2) |
| 6 | 1/4″-20 hex bolt, silicon bronze, **1″** | through-bolt + jam nut | 10/18 AWG HV landings |
| 10 | 5/16″-18 hex nut + USS flat washer (silicon bronze) + SS Belleville | bronze nuts/flats; SS spring | 2/0 clamp (nut + jam nut) |
| 12 | 1/4″-20 hex nut + USS flat washer (silicon bronze) + SS Belleville | bronze nuts/flats; SS spring | small HV clamp (nut + jam nut) |
| 3 | **SM40-M10** busbar standoff | BMC, 40 mm tall, 40 mm face / 34 mm waist, **M10** inserts 11 mm both ends, 1000 VAC / 1500 VDC | 1 per bar, under the center; **not** battery-box mounts |
| 6 | M10 × 20 mm hex bolt + M10 flat washer | SS or zinc | 1 through bar into SM40 top; 1 from chassis into SM40 bottom |
| 1 | M10 nut + M10 flat washer, 316 SS | SW1 output stud through TB1; torque 90–100 in·lb |

Use **1/4″** rings on the small studs (1/4-20 through-bolts). 2/0 still lands on **5/16″**.

Do **not** land a cable on the center M10 — that bolt only clamps the bar to the SM40. Torque the M10 to the insulator rating (typically ~15 N·m), not lug torque.

---

## 7. Optional / tooling

| Qty | Item | Why |
| --- | --- | --- |
| 1 | 2/0 lug crimper (dies for 2/0 DLO) | traction cable |
| 1 | Weather Pack crimper + cavity tool | 4-way bulkhead |
| 1 | Deutsch DTM (size 16) crimper | inverter CAN |
| 1 | 14 / 18 AWG insulated-terminal crimper | QC and rings |
| — | HV cable loom, orange tape, warning labels | pack / charger DC / DCIS HV |

---

## 8. Do not buy (included or unused)

| Item | Why |
| --- | --- |
| TSM2500 AC DJ7031 pigtail, DC SB50 pigtail, CAN pair | ships with charger |
| DCIS dj70310 / DJ7021 pigtails | ships with DCIS |
| Orion CWHMIO 18 AWG Main I/O | ships with this BMS |
| HyPer 9 K1 AMPSEAL harness | ships with inverter |
| CANdapter USB-B cable | ships with adapter (add bulkhead only if you want a dash port) |
| Blue Sea circuits 1, 3, unused 6 | unused on this sheet (Always_Hot circuit 4 is Dash/Pi) |
| Orion fan pins 9 and 10 | no-connect |
| Tesla cell taps on this schematic | separate Orion tap harness |

---

## 9. Schematic vs this list

- Kill switch: **Rincon HVBD6AXR** (600 A, no aux, red).
- K4: **Omron G9EJ-1-E-UVD DC12** only — polarized HV contacts, 12 V coil.
- F5 and F6 are both **MAXI 50 A**; all 10 AWG 12 V is **GXL** (schematic GLX).
- Traction 2/0 is **orange** with red/black heatshrink at the lugs.
- Vehicle DCIS pack HV is **red / black** 10 AWG HV, same cable as charger DC (factory pigtail stays yellow / gray).
- Precharge wire is unlabeled on the sheet; buy **18 AWG HV** red.
- RAC02 taps: buy **18 AWG 300 VAC** (schematic also says 18AWG AC).
- J1772 symbol reference is `J1773`.
- SW5 **Instruments** is a dash SPST on Always_Hot **Dash/Pi**. Ready/Precharge is not gated. Pi 5 + Touch Display 2 10″ + PiCAN 3 run from the PiCAN **3 A SMPS**.
- Circuit_Breaker3 is the second pole of the **32 A** charger DC breaker; Circuit_Breaker4 is the second pole of the **10 A** DCIS breaker.
- TB1/TB3 (`Terminal_Block+`) and TB2 (`Terminal_Block−`): small studs are **1/4-20**. 2/0 still lands on **5/16″**.

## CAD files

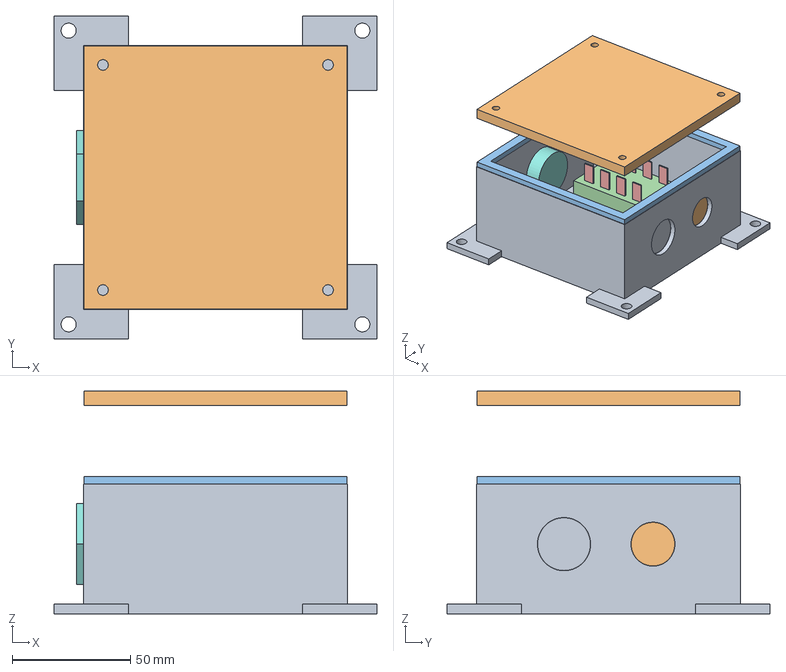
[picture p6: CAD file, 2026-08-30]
ac enclosure/ac_enclosure_4x4x2_assembly.step
136.5 x 136.5 x 94.1 mm

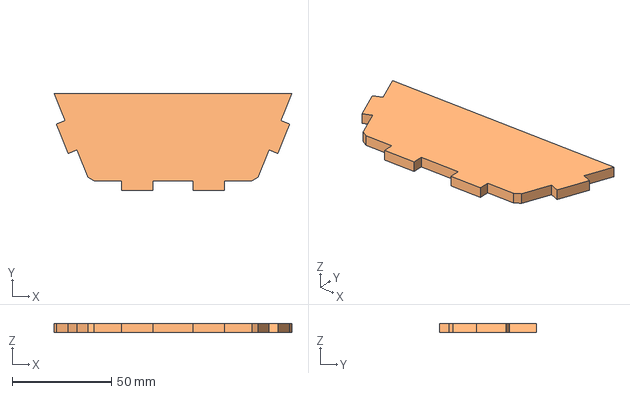
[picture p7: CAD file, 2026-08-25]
battery box mounts/battery box mounts-Assemblybacking plate.step
120.1 x 49.1 x 4.75 mm

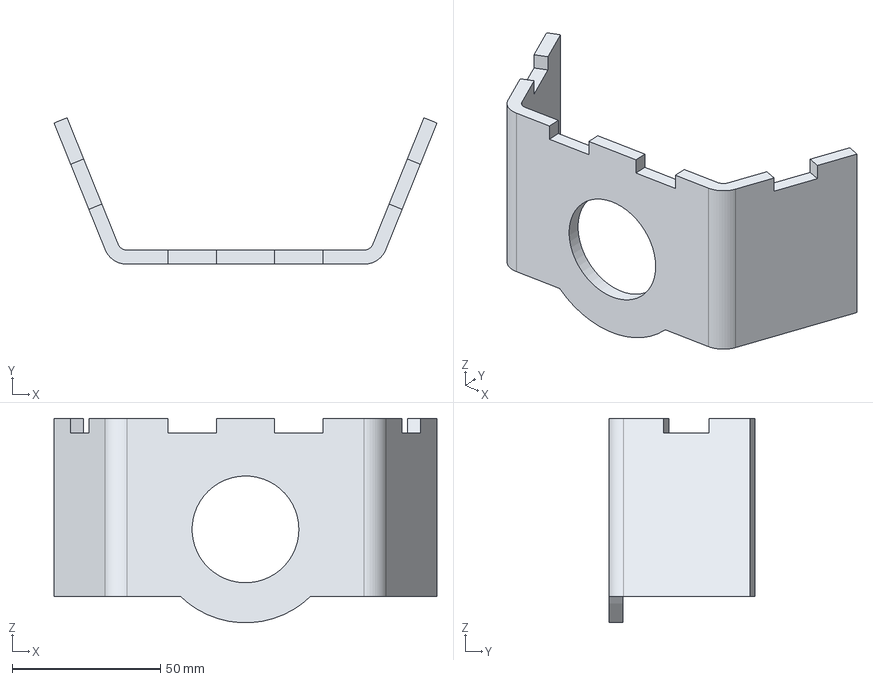
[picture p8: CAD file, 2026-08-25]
battery box mounts/battery box mounts-Assemblymain bracket.step
129.2 x 49.4 x 68.9 mm

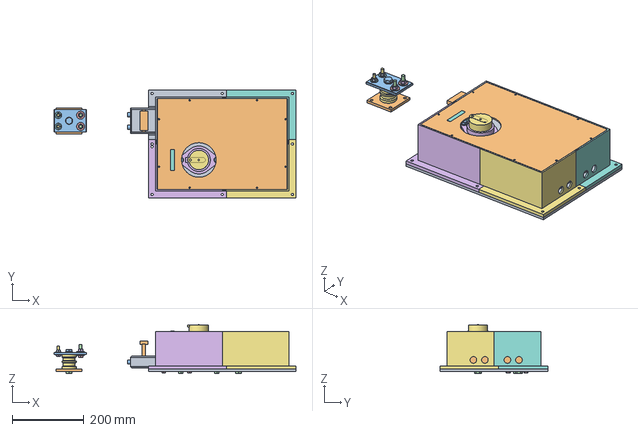
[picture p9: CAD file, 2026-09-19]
bus bars/bus_bars_assembly.step
672.6 x 300.4 x 137.0 mm

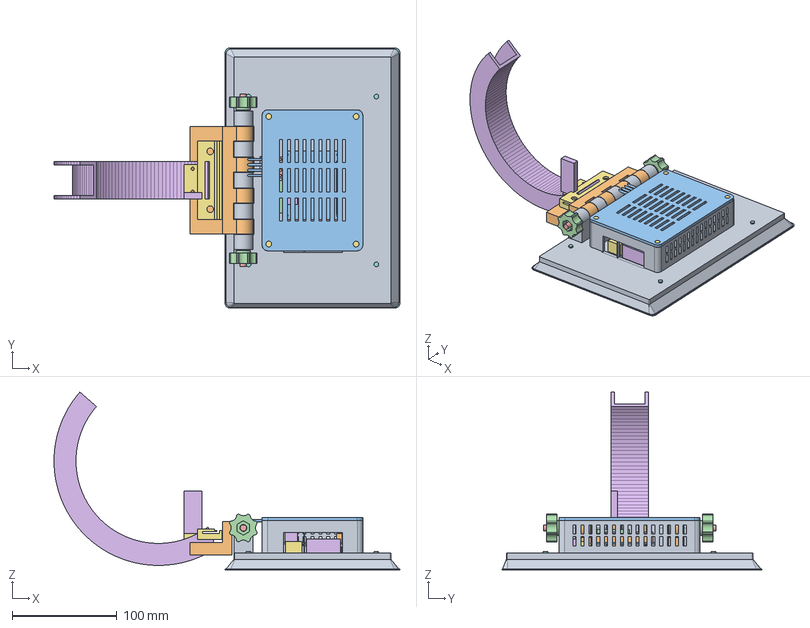
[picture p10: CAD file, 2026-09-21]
dashboard/mount/mount_assembly.step
329.8 x 248.1 x 169.6 mm

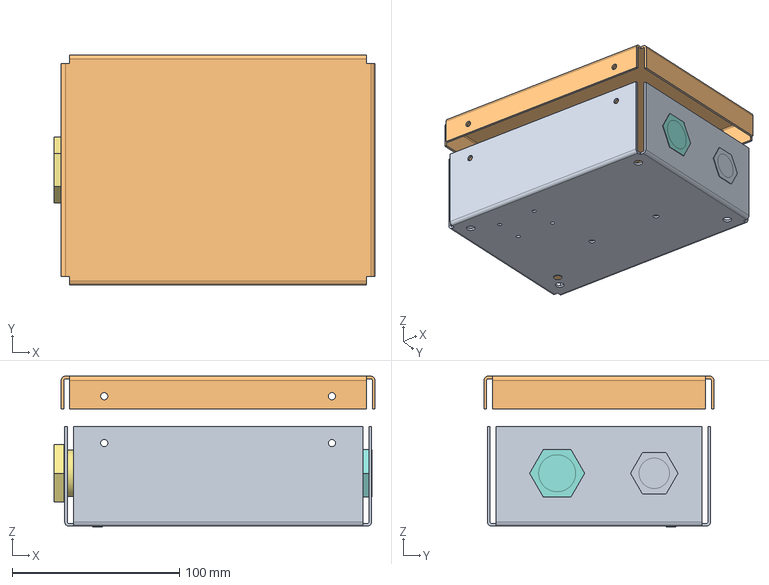
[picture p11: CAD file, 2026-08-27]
ac enclosure/ac_enclosure_assembly.step
191.7 x 137.4 x 90.0 mm

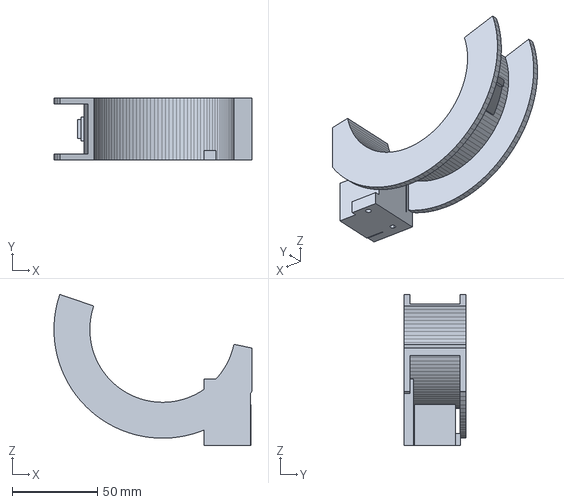
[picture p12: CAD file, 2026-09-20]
dashboard/mount/mount-AssemblyStow_Rail_Arc.step
115.8 x 36.0 x 88.4 mm

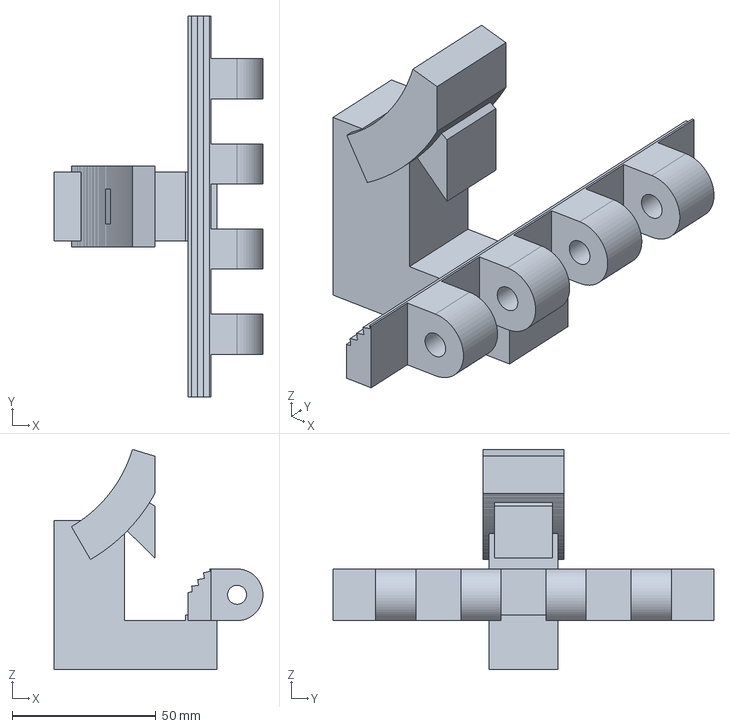
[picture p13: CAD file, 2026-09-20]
dashboard/mount/mount-AssemblyMount_Bracket.step
72.6 x 132.4 x 76.5 mm

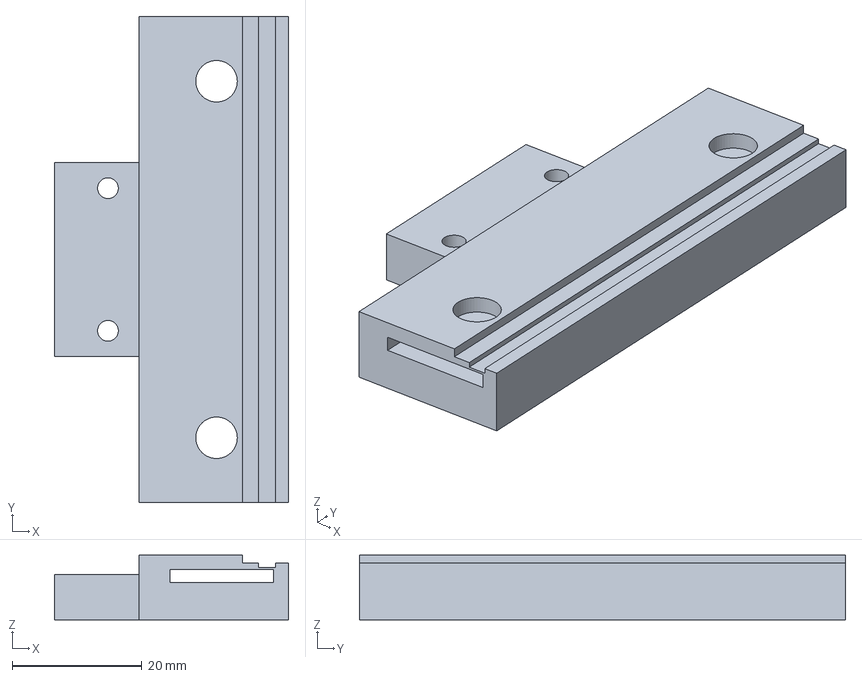
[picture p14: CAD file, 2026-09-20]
dashboard/mount/mount-AssemblyStow_Rail_Clamp.step
36.1 x 75.0 x 10.0 mm

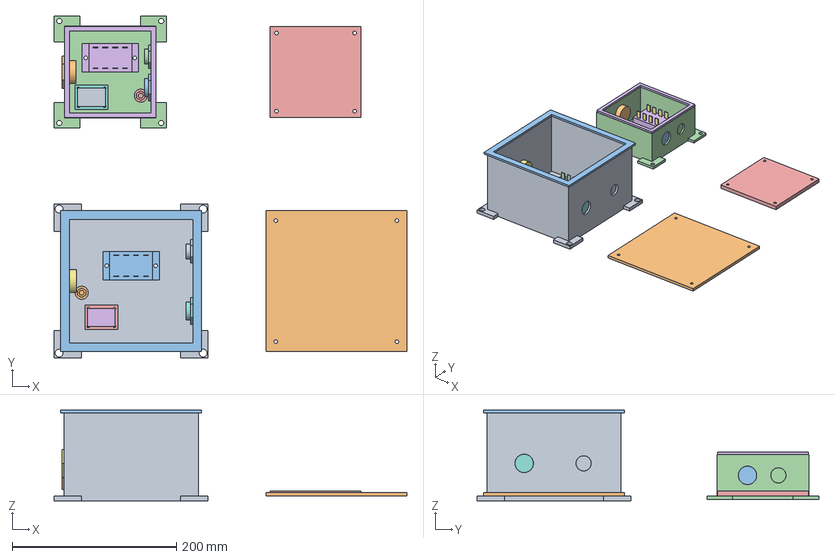
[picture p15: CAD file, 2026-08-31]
ac enclosure/ac enclosure.FCStd
429.4 x 416.5 x 110.4 mm
Cantex_664
Cantex_Cover_664
T92_664
T92_QC_664
RAC02_PCB_664
RAC02_664
Gland_J1772_664
Gland_DJ7031_664
Gland_Signal_664
PE_Stud_664
Gasket_664
Cantex_442
Cantex_Cover_442
T92_442
T92_QC_442
RAC02_PCB_442
RAC02_442
Gland_J1772_442
Gland_DJ7031_442
Gland_Signal_442
PE_Stud_442
Gasket_442

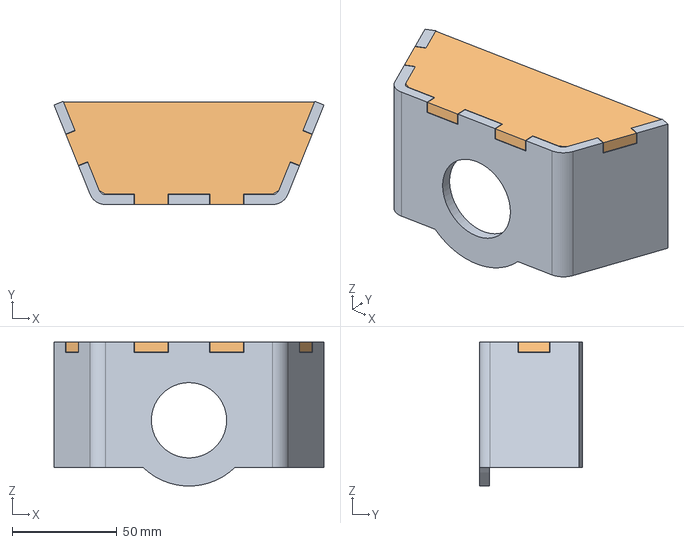
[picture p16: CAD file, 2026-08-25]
battery box mounts/battery box mounts.FCStd
129.2 x 49.4 x 68.9 mm
plate

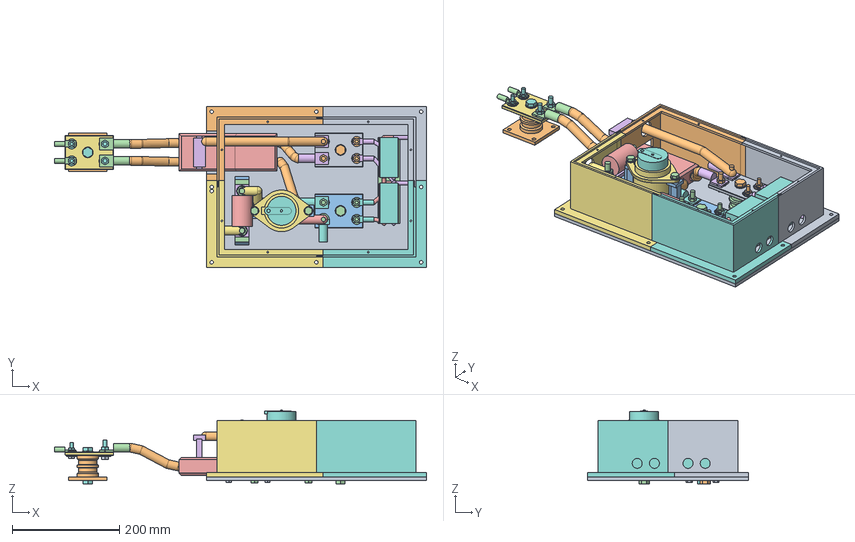
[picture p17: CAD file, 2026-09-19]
bus bars/bus bars.FCStd
692.6 x 300.4 x 137.0 mm
Plate_Pack
Plate_TB3
TB1_PackPlus_Rear_Copper
TB1_PackPlus_Rear_Hardware
TB1_PackPlus_Rear_StudHeadsBottom
TB1_PackPlus_Rear_SM40
TB1_PackPlus_Rear_Inserts
TB1_PackPlus_Rear_LugKeepout
TB2_PackMinus_Copper
TB2_PackMinus_Hardware
TB2_PackMinus_StudHeadsBottom
TB2_PackMinus_SM40
TB2_PackMinus_Inserts
TB2_PackMinus_LugKeepout
TB3_PackPlus_Inverter_Copper
TB3_PackPlus_Inverter_Hardware
TB3_PackPlus_Inverter_StudHeadsBottom
TB3_PackPlus_Inverter_SM40
TB3_PackPlus_Inverter_Inserts
TB3_PackPlus_Inverter_LugKeepout
SB350_Housing
SB350_Handle
SB350_Contacts
SB350_Mounts
SB350_MountHW
SB350_DLO
F4_Mounts
F4_Hardware
F4_Body
F4_Blades
F4_DLO
CB_Bodies
CB_Toggles
CB_PlusMark
CB_MinusMark
CB_DIN
CB_DLO_Pos
CB_DLO_Neg
SW1_Body
SW1_Handle
SW1_Studs
SW1_Bushings
SW1_Mounts
SW1_MountHW
SW1_Jumper
SW1_InputLug
Cover_SW
Cover_SE
Cover_NE
Cover_NW

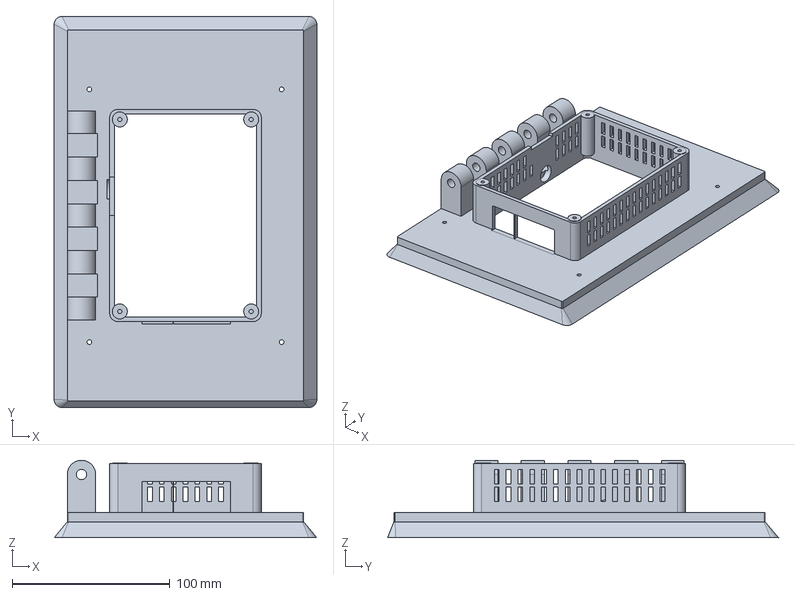
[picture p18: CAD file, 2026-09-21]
dashboard/mount/mount_plate.step
166.4 x 247.6 x 49.0 mm

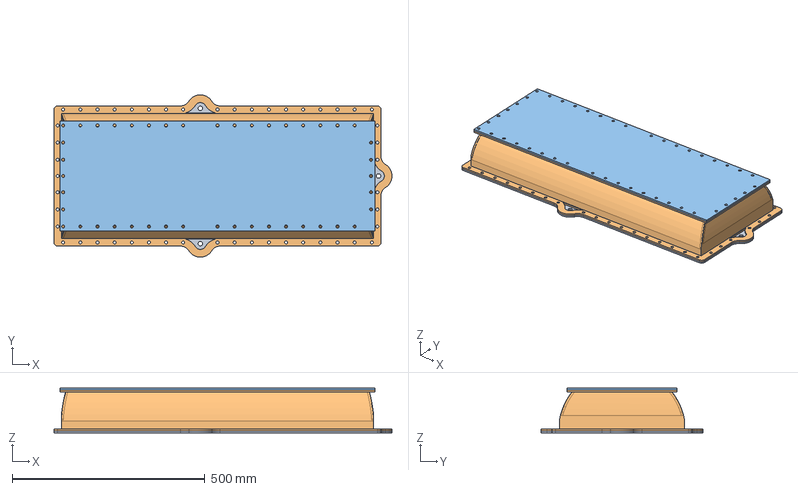
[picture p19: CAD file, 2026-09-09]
futuristic power/power station.FCStd
876.2 x 420.6 x 115.8 mm
base plate
lower base003
top plate

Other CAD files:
thru wall terminals/ThruWall_M8.step
bus bars/bus bars-Cover_NW.step
dashboard/mount/mount_bracket.step
futuristic power/bottom_1x.FCStd
ac enclosure/ac enclosure-Box_5052.3mf
ac enclosure/ac enclosure-Box_5052.step
ac enclosure/ac enclosure-Lid_5052.3mf
ac enclosure/ac enclosure-Lid_5052.step
ac enclosure/ac_box.step
ac enclosure/ac_box_4x4x2.step
ac enclosure/ac_lid.step
ac enclosure/ac_lid_4x4x2.step
battery box mounts/battery box mounts-Assemblybacking plate.3mf
bus bars/bus bars-Cover_NW.3mf
bus bars/bus bars-Master_CopperBar.step
bus bars/bus bars-TB2_PackMinus_Copper.3mf
bus bars/bus bars-TB2_PackMinus_Copper.step
bus bars/bus bars-TB3_PackPlus_Inverter_Copper.3mf
bus bars/bus bars-TB3_PackPlus_Inverter_Copper.step
bus bars/copper_bar.step
bus bars/copper_bar_tb1.step
bus bars/cover_lid_pc.step
bus bars/cover_lid_pc.stl
bus bars/cover_ne.step
bus bars/cover_ne.stl
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

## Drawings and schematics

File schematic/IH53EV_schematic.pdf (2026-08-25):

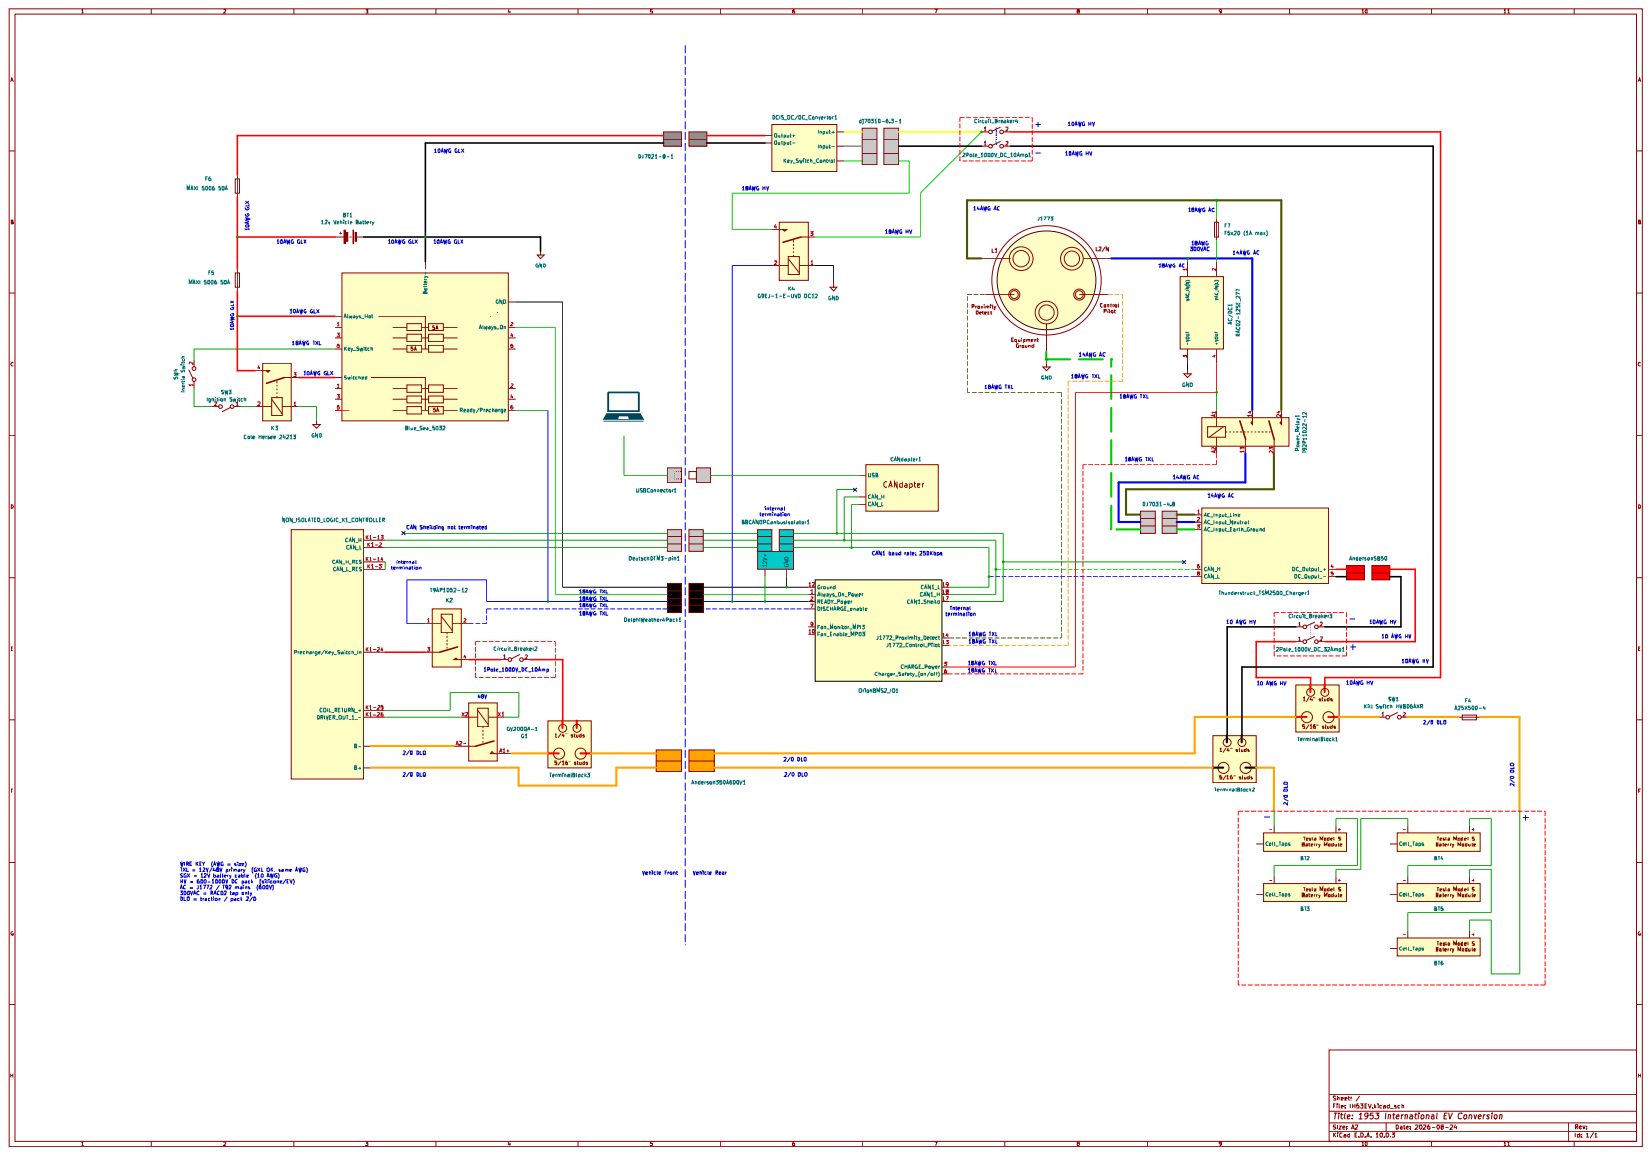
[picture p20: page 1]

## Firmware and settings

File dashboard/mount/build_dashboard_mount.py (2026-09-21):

# Rear mount for Raspberry Pi Touch Display 2 10" + Pi 5 + PiCAN 3.
# Run inside FreeCAD. Units: mm. ASCII only.
#
# Display dims from Raspberry Pi product brief RP-010276-MM (10" Portrait):
#   glass 166.88 x 248.096, R=5; rear aluminum 143.36 x 228.73, sharp corners.
#   Glass overhang vs aluminum: 11.76 sides, 11.86 top, 7.51 bottom.
#   Four chassis bosses 121.8 x 160 (M2.5 through the plate into those
#   3 mm threaded standoffs). Four Pi standoffs
#   49 x 58, 5 mm tall, 90.06 mm from rear top to the upper pair.
# Side stack (drawing): glass 1.1 + aluminum 5.95 = 7.05 glass-front to
# aluminum-back. Plate sits on the 3 mm rear standoffs; the bevel wraps
# from those standoff tops to the glass front (7.05 + 3).
# Hood is fused to the plate (one print) over the Pi 5 + PiCAN 3,
# 31 mm inner height, with USB/Ethernet windows on the USB short edge and a
# USB-C cable hole on the long edge opposite GPIO (adjacent to Ethernet).
# Lid is a separate 4x M3 self-tap cover.
# Hinge barrels sit on the cabin face of the USB-C long edge (-X), raised
# so the pin is in the clear; a tunnel under the barrels lets the USB-C
# cable plug in. M6 threaded rod + printed round knobs set friction.
# Truck bracket fingers mesh between those barrels. 4x M2.5 through the
# plate into the display tabs (no counterbore).
# Stow: hidden arc behind IH dash (radio..glovebox bay). Plate-side hinge
# fixed; truck-side bracket carries the rail tongue. Only a small lip
# clamp is visible when stowed. Articulate: Stow + Tilt (no yaw yet).
# PiCAN 3 Rev C: 40-pin GPIO along one long edge; DB9 + 4-way screw terminal
# on the opposite long edge. Terminal silkscreen (user guide): 1 CAN_H,
# 2 CAN_L, 3 GND, 4 +12V. Four-wire gland is on the USB-C wall (-X).
# Wires: CAN-PI-H, CAN-PI-L, 12-PISW, 12-PIGND (schematic/wires.md).
#
# Z=0 is the outer face of the display rear aluminum (the 5.95 mm block).
# +Z is toward the cabin. Glass front is at Z=-7.05. Screw standoffs stick
# +3 mm from Z=0; the plate seats on those.
# Origin XY is the centre of the rear metal. +Y is portrait-screen up.
#
# Print PETG (supports OK: hinge and hood stand on the cabin face):
#   plate     -- wrap/glass rim on the bed. Hood walls and hinge print up.
#                Support the aluminum-pocket roof.
#   bracket   -- truck foot on the bed, knuckles up.
#   knob      -- stand-off boss on the bed (hinge side). Two of them.
#                Drop an M6 hex nut in the pocket on the opposite face.
#   lid       -- flat cover on the bed, M3 seats facing up.
#   stow_rail_arc   -- hidden C-channel behind dash (tongue slides in it).
#   stow_rail_clamp -- lip clamp; 2x M3 to the arc foot. Only cabin-visible bit.
#   bracket         -- knuckles + arm + tongue (rides the arc channel).

import math
import os

import FreeCAD as App
import Part

try:
    import FreeCADGui as Gui
except ImportError:
    Gui = None

OUT_DIR = "/Users/sfeldma/work/ih-53-ev/dashboard/mount"
DOC_NAME = "DashboardMount"

# --- Touch Display 2 10" (product brief physical spec) ---
GLASS_W = 166.88
GLASS_H = 248.096
GLASS_R = 5.0
# Aluminum chassis corners are sharp (not the glass R5). Tiny break-edge for FDM.
AL_R = 0.8
REAR_W = 143.36
REAR_H = 228.73
GLASS_T = 1.1
FRONT_STACK = 7.05
REAR_T = FRONT_STACK - GLASS_T
OVERALL_T = FRONT_STACK
BOSS_H = 3.0
REAR_TOP_INSET = 11.86
GLASS_SIDE = (GLASS_W - REAR_W) / 2.0
Z_GLASS_FRONT = -OVERALL_T
# Wrap wall ~2.8 mm (was 0.8 at the aluminum root; PETG snapped).
AL_POCKET_CLR = 0.4
WRAP_WALL = 2.8
BACK_LIP = AL_POCKET_CLR + WRAP_WALL
WRAP_INSET = 0.25
FRONT_RIM = WRAP_WALL
BOSS_FROM_TOP = 34.56
BOSS_FROM_SIDE = 10.78
MOUNT_DX = 121.8
MOUNT_DY = 160.0
PI_HOLE_DX = 49.0
PI_HOLE_DY = 58.0
PI_HOLE_FROM_TOP = 90.06
PI_STAND_H = 5.0
PI_STAND_OD = 5.0
M25 = 2.5

# --- Pi 5 ---
PI_L = 85.0
PI_W = 56.0
PI_T = 1.6
PI_HOLE_EDGE = 3.5
USB_H = 16.0
ETH_H = 13.5
# RP-008347-DS: USB-C / dual micro-HDMI sit on the long edge opposite
# GPIO (drawing bottom). 11.2 is the USB-C centre from the left short
# edge. USB/Ethernet envelopes from STEP, same edge as datum (Y=0).
USBC_FROM_LEFT = 11.2
USBC_W = 8.94
HDMI0_FROM_LEFT = 25.8
HDMI1_FROM_LEFT = 39.2
ETH_FROM_USBC_EDGE = (2.25, 18.15)
USB_FROM_USBC_EDGE = (22.30, 54.66)

# --- PiCAN 3 HAT (HAT outline + DB9 / 4-way 5.08 mm terminal) ---
HAT_L = 65.0
HAT_W = 56.5
HAT_T = 1.6
HAT_GAP = 11.0
TERM_PITCH = 5.08
TERM_N = 4
TERM_H = 10.0
TERM_W = 8.2
DB9_L = 31.0
DB9_W = 12.6
DB9_H = 12.5
DB9_OVERHANG = 10.0
INDUCTOR_S = 12.0
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

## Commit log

2026-08-18 add kicad schematic
    [IH53EV.kicad_pcb, IH53EV.kicad_sch]
2026-08-22 working on schematic
    [IH53EV.kicad_sch]
2026-08-23 add wires.md
    [IH53EV.kicad_sch]
2026-08-25 getting ready for sendcutsend
    [battery box mounts.FCStd]
2026-08-25 3d printing to get it right
    [IH53EV.kicad_sch, battery box mounts-Assemblybacking plate.step, battery box mounts-Assemblymain bracket.step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]
2026-08-25 sending to sendcutsend
    [battery box mounts-Assemblybacking plate.step, battery box mounts-Assemblymain bracket.step, battery box mounts.FCStd]
2026-08-27 add AC enclosure and bus bars
    [IH53EV.kicad_sch, ac enclosure-Box_5052.step, ac enclosure-Lid_5052.step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]
2026-08-30 serveral options for ac enclosure box
    [ac enclosure-Box_5052.3mf, ac enclosure-Lid_5052.3mf, ac enclosure.FCStd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]
2026-08-31 add thru-wall terminals
    [IH53EV.kicad_sch, ThruWall_M8.step, ac enclosure.FCStd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]
2026-09-09 add dashboard
    [IH53EV.kicad_sch, bottom_1x.FCStd, bottom_1x.dxf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]
2026-09-10 update bus bar
    [IH53EV.kicad_sch, bus bars.FCStd, bus_bars_assembly.step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]
2026-09-11 futzing with bus bar
    [IH53EV.kicad_sch, bus bars-TB3_PackPlus_Inverter_Copper.3mf, bus bars-TB3_PackPlus_Inverter_Copper.step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]
2026-09-19 add dashboard mount
    [bus bars-TB3_PackPlus_Inverter_Copper.3mf, bus bars.FCStd, bus_bars_assembly.step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]
2026-09-19 reduce enclosure size for HV
    [bus bars-Cover_NW.step, bus bars.FCStd, bus_bars_assembly.step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]
2026-09-19 refine dashbaord enclosure
    [bus bars-Cover_NW.3mf, bus bars.FCStd, mount-Hinge_Knob_A.step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]
2026-09-19 adjust dashboard mount knobs
    [bus bars.FCStd, mount-Hinge_Knob_A.step, mount-Hinge_Knob_B.step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]
2026-09-20 guide rail for dashboard
    [mount-AssemblyMount_Bracket.step, mount-AssemblyStow_Rail_Arc.step, mount-AssemblyStow_Rail_Clamp.step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]
2026-09-21 working on dashboard bracket
    [mount-AssemblyMount_Bracket.3mf, mount.FCStd, mount_assembly.step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]
